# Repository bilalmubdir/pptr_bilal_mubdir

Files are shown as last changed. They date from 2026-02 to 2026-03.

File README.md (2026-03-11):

<table align="center">
  <tr>
    <!-- Left: PNG image (30%) -->
    <td width="30%" align="center" valign="middle">
      
    </td>
    <!-- Right: SVG banner (70%) -->
    <td width="70%" align="center" valign="middle">
      
    </td>
  </tr>
</table>

# Propeller Performance Test Rig Documentation




<div> <a href="https://certification.oshwa.org/uk000089.html"></div>

## 📚 Citation
If you use this repository in academic work:

```bibtex
@misc{pptrBilal2026,
  author       = {Mubdir, Bilal and Prempain, Emmanuel},
  title        = {Propeller Performance Test Rig Documentation},
  month        = mar,
  year         = 2026,
  publisher    = {Zenodo},
  version      = {v1.0.3},
  doi          = {10.5281/zenodo.18955065},
  url          = {https://doi.org/10.5281/zenodo.18955065},
}
```

## 📘 Overview
This repository contains open‑source engineering documentation for the Propeller Performance Test Rig, including mechanical drawings, circuit schematics, block diagrams, and specification tables.

<p align="center">
  
</p>
<!-- The materials accompany the research paper: -->
<!-- 
> **"Propeller Performance Test Rig"**  
> *Author: Bilal Mubdir, Research Postgraduate*  
> *Affiliation: University of Leicester*  
-->

All diagrams and documents are provided under the **CERN Open Hardware License – Strongly Reciprocal (CERN‑OHL‑S)**, enabling transparent reuse and modification for academic and engineering purposes. 

## 📁 Repository Structure
```
docs/
├── figures/
│   ├── mechanical/     # PDFs of CAD, enclosure, and mechanical drawings
│   ├── electrical/     # Circuit schematics, PCB module diagrams
│   └── misc/           # other figures and diagrams
├── CAD/                # The SolidWorks CAD files of the PPTR mechanical design
├── scripts/            # Python Remote Client Application and ESP12F/NodeMCU Firmware
├── lib/                # C++ libraries for the ESP12F/NodeMCU Firmware
└── tables/             # LaTeX tables (specifications, BOM, etc.)
```

## 📄 Contents
#### **Figures**
- Mechanical drawings (exploded views, dimensions)
- Electrical schematics (DAQ, sensors, control modules)
#### **CAD**
- Mechanical design raw CAD files (SolidWorks 2025)
#### **Tables**
- Technical specifications
#### **Scripts**
- Codes and scripts used for the PPTR system 
#### **Libraries**
- C++ libraries for ESP12F/NodeMCU Firmware

## 🛠 Usage
- Access diagrams under `docs/figures/`
- Import tables into your paper from `docs/tables/`

## 📐 Sensor Calibration Instructions (Thrust & Torque Load Cells)
This section provides practical, step‑by‑step instructions for calibrating the thrust load cell and the left/right torque load cells used in the PPTR measurement system.

### 🚀 1. Thrust Load Cell Calibration
The thrust load cell measures vertical thrust generated by the rotor. To calibrate it:

#### 1.1. Setup
* Mount the PPTR vertically (rotor pointing downward).
* Fix the structure onto a rigid support so it cannot move.
* Attach the calibration weight (standard dead load) to the rotor as shown:
<p align="center" >
  
</p>

#### 1.2. Procedure
1) Connect the thrust load cell to its HX711 module.
2) Hang a series of known calibration weights (Loadₛₜd) to generate reference thrust forces.
3) For each weight:
    - Record the raw HX711 output.
    - Remove the weight before applying the next one.

#### 1.3. Result
A linear mapping between Raw load cell voltage, and True thrust force (g)should be computed. The **thrust calibration scale factor** then determined from this mapping.

### 🌀 2. Torque Load Cell Calibration (Left & Right)
The PPTR includes **two torque load cells**, one on each side of the rotor axis. Calibration is performed with the device in its **normal horizontal operating orientation**.

#### 2.1. Setup
* Install the PPTR horizontally on its base.
* Attach the aluminum torque calibration stripe to the calibration lever.
* This stripe has two symmetric holes on each side of the rotor center, at 50 mm and 100 mm. These holes serve as Calibration Reference Points (CRP).
* The calibration process consists of two steps: tare and measure.
<p align="center" >
  
</p>

#### 2.2. Tare Both Torque Load Cells - Step (1)
Before taking any calibration measurements:
1) Place the calibration weight (standard dead load) at CRP‑0 (center of the rotor).
2) Perform a tare (zero) on both channels to nullify rotor, brackets, and any sensor bias.

#### 2.3. Take Calibration Measurements - Step (2)
1) Move the calibration weight to one of the CRPs (50 mm or 100 mm).
2) Record raw left and right torque sensor readings.
3) Move the weight to the symmetric CRP on the opposite side.
4) Repeat measurements using multiple Loadₛₜd values.

This creates symmetric torque reference conditions on both sides

#### 2.4. Result
A linear mapping between Raw load cell voltage and True torque force (N·m) should be computed. The **Torque calibration scale factor** for each sensor is then determined from its corresponding mapping.

<!---->
## 📡 Remote Client Command List
The following commands are used to control the PPTR, operate the motor, read sensors, and perform calibration routines from the Remote Client Application.

| Command |  Syntax  | Description | Input Range / Notes |
|---|---|---|---|
| **Send ESC signal + read sensors** | `CM1,<X>` | Sends ESC control signal *and* reads thrust/torque sensors. | `X = 0–180` (Speed → 0–Max) |
| **Send ESC signal only** | `CM2,<X>` | Drives the ESC without reading sensors. | `X = 0–180` (Speed → 0–Max) |
| **Read sensors only** | `CM3` | Reads thrust and torque sensor values. | No input |
| **ESC calibration routine** | `CM4,<X>` | Used to set ESC calibration points. | `X = 0` → min pulse<br>`X = 1` → max pulse |
| **Tare thrust & torque sensors** | `CM5` | Zeros all load cell readings before measurement. | No input |
| **Safe motor shutdown** | `CM6` | Gradually reduces ESC signal to zero. | No input |
| **Safe motor startup** | `CM7,<X>` | Starts motor safely and ramps signal to target value. | `X = 0–180` (Speed → 0–Max) |
| **System status check** | `CM8` | Reports system status, and safety flags. | No input |

### Notes
- Commands are case-insensitive unless otherwise specified.
- Always run `CM5` (tare) after powering the device or repositioning sensors.
- Calibration (`CM4`) is needed only after replacing ESC or motor hardware.
- Safe start/stop commands (`CM7`, `CM6`) are recommended over issuing raw ESC commands.

## 🧩 Using the Code in This Repository

The PPTR software consists of **two components**:

1) **Python Remote Client Application** (runs on your PC/laptop)  
2) **ESP12F / NodeMCU firmware** (C++ for Arduino IDE)

Both code files are located in:

    docs/scripts/

Required libraries for the firmware are provided in:

    docs/lib/

### 1) Remote Client Application (Python)

**File location**

    docs/scripts/remote_client.py

**What it does**
- Connects to the PPTR’s Wi‑Fi hotspot  
- Sends user commands (CM1–CM8) to the NodeMCU over UDP  
- Streams and plots real‑time sensor data  
- Logs measurements to a CSV file

**Dependencies**

Install the required Python package:

    pip install matplotlib

(Modules `socket`, `time`, `threading`, `queue`, `sys`, and `select` are part of the standard library.)

**Choose the CSV output filename**

Inside the script, edit the line:

    csv_filename = "sensor_data.csv"

Change the value to set the name of your collected data file.

**How to run**

1. Power the PPTR and wait for its Wi‑Fi hotspot.  
2. Connect your computer to:
   
       SSID: ESP-12F/NodeMCU Access Point name
       PASS: chosen password in ESP-12F/NodeMCU Access Point settings

3. Start the client:

       python remote_client.py

4. The script will start plotting live data and append rows to the CSV file.
5. You can send any command from the [command list](#commandsList), except CM3, as this is used continuously to collect data.
6. To stop, type:

       exit

A final static plot will be shown before the program exits.

### 2) ESP12F / NodeMCU Firmware (C++ for Arduino IDE)

**File location**

    docs/scripts/pptr_firmware.cpp

**What it does**

- Creates a Wi‑Fi Access Point and listens for UDP commands  
- Controls the ESC (safe start/stop + direct control)  
- Reads load cells (HX711), tachometer pulses, and INA226 power sensor  
- Streams sensor data back to the Python client

**Arduino libraries (provided)**

All required libraries are included here:

    docs/lib/

Copy everything inside `docs/lib/` to your Arduino libraries folder, restart the Arduino IDE so it detects the libraries.

**Board support and upload (Arduino IDE)**

1. Install the ESP8266 board support:
   
       Arduino IDE → File → Preferences
       Additional Boards Manager URLs:
       http://arduino.esp8266.com/stable/package_esp8266com_index.json

   Then go to:
   
       Tools → Board → Boards Manager → search “ESP8266” → Install

2. Select the board:

       Tools → Board → NodeMCU 0.9 (ESP-12E Module)

3. Open the firmware file and upload:

       File → Open → docs/scripts/pptr_firmware.cpp
       Upload

After upload, the controller will broadcast its hotspot and accept UDP commands.

## 📚 Citation
If you use this repository in academic work:

```bibtex
@misc{pptrBilal2026,
  author       = {Mubdir, Bilal and Prempain, Emmanuel},
  title        = {Propeller Performance Test Rig Documentation},
  month        = mar,
  year         = 2026,
  publisher    = {Zenodo},
  version      = {v1.0.3},
  doi          = {10.5281/zenodo.18955065},
  url          = {https://doi.org/10.5281/zenodo.18955065},
}
```

## 🤝 Contributing
Contributions are welcome!
Please:

- Follow the folder structure
- Include clear commit messages
- Provide PDFs for all figures
<!-- ## 🧩 Maintainers
- Bilal Mubdir
- Research
- Email: bama4@le.ac.uk / bilal.mubdir -->

## License
This project is licensed under the CERN Open Hardware License Version 2 – Strongly Reciprocal (CERN‑OHL‑S).

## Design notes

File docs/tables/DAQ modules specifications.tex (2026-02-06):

\begin{table*}[t]
    \centering
    \footnotesize
    \caption{Summary of modules used in the DAQ system.}
    \begin{tabular}{>{\raggedright}p{3.5cm} >{\centering}p{1.8cm} >{\centering}p{3cm} >{\raggedright\arraybackslash}p{7cm}}
        \toprule
        \bf{Module}  & \bf{Quantity} & \bf{Function} & \bf{Specifications}\\
        \midrule
        NodeMCU & 1 & \thead[c]{Micrcontroller\\and Wi-Fi\\proxy} & \thead[l]{CPU Speed: \SI{160}{\mega\hertz}, Wi-Fi: 802.11 b/g/n, \SI{2.4}{\giga\hertz},\\
                                                                                Memory: 32 Mbit, Voltage: 3-\SI{3.6}{\volt}}\\
                                                                                Interfaces: UART, GPIO, PWM, I$^2$C\\                                      
        CJMCU-266 & 3 & \thead[c]{Measuring\\electrical\\parameters} & \thead[l]{Interface: I$^2$C or SMBus compatible,\\	
                                                                                Measured Voltage: 0-\SI{36}{\volt}, Current Range: \SI{-20}{\milli\ampere} to \SI{20}{\milli\ampere},\\
                                                                                Supply Voltage:	2.7-\SI{5.5}{\volt}, Accuracy: 0.1\% max gain error,\\
                                                                                Max offset:  \SI{10}{\micro\volt}, Resolution:	16-bit for}\\ 
         
        HX711 & 1 & \thead[c]{ADC\\for load cells\\signals} & \thead[l]{ADC Resolution: 24-bit, Input Channels: 2 differential,\\
                                                                                Voltage: 2.6-\SI{5.5}{\volt}, Current: $<$\SI{1.5}{\milli\ampere},\\       
                                                                                Data Rate: up to 80 sample/s,  Interface: Simple 2-wire serial}\\                                                                                               
        \bottomrule
    \end{tabular}
    \label{tab: ch3 DAQ componenets}
\end{table*}

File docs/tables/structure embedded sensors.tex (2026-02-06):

\begin{table}[H]
    \centering
    \footnotesize
    \caption{Summary of the sensors embedded in the PPTR Structure.}
    \begin{tabular}{>{\raggedright}p{1.2cm} >{\centering}p{0.8cm} >{\centering}p{1.7cm} >{\raggedright\arraybackslash}p{2.1cm}}
        \toprule
        \bf{Component}  & \bf{Quantity} & \bf{Function} & \bf{Specifications}\\
        \midrule
        Load cell & 1 & Thurst measurement & \thead[l]{Range: 0-\SI{1}{\kilogram},\\
                                               Voltage: 5-\SI{12}{\volt},\\
                                               Precision: $\mp$\SI{1}{\gram}}\\
        Load cell & 2 & Torque measurement & \thead[l]{Range: 0-\SI{1}{\kilogram},\\
                                               Voltage: 5-\SI{12}{\volt},\\
                                               Precision: $\mp$\SI{1}{\gram}}\\ 
        Infrared sensor & 1 & Rotational speed sensor & \thead[l]{Range: 1-\SI{38}{\kilo\hertz},\\
                                                               Voltage: 3-\SI{5}{\volt},\\
                                                               Detection angle: $35^{\circ}$}\\                             
        \bottomrule
    \end{tabular}
    \label{tab: ch3 PPTR sensors}
\end{table}

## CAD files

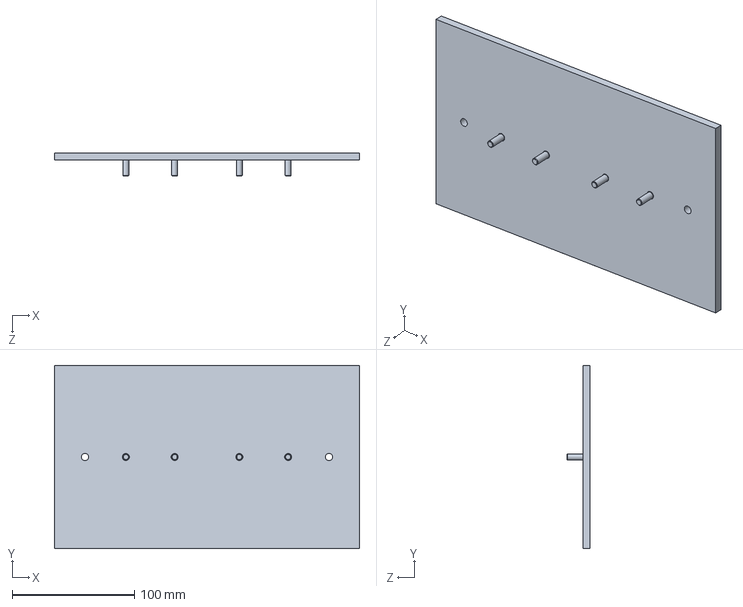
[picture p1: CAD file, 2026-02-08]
docs/CAD/main_base.SLDPRT
250.0 x 150.0 x 19.0 mm

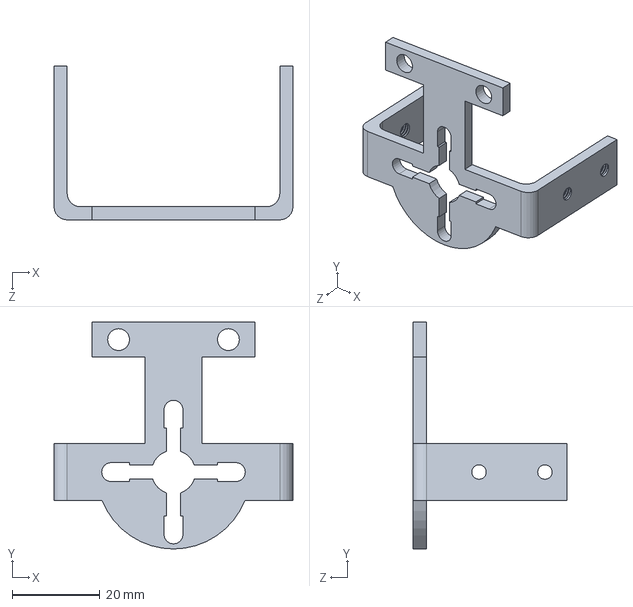
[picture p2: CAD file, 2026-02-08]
docs/CAD/rotor_mounting_bracket.SLDPRT
54.4 x 51.7 x 35.0 mm

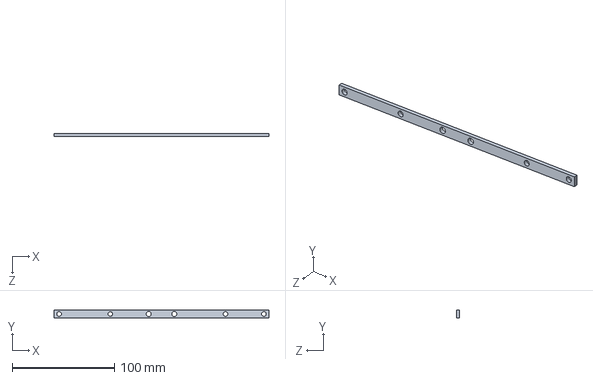
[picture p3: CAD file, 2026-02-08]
docs/CAD/calibration_strip.SLDPRT
210.0 x 8.00 x 3.00 mm

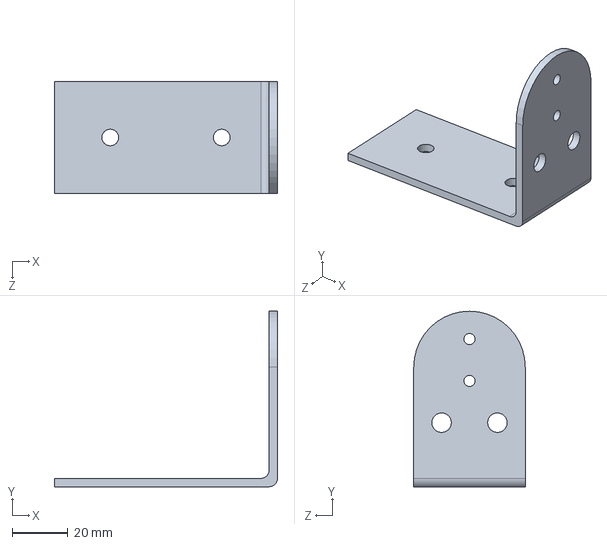
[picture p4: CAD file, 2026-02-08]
docs/CAD/lower_support_brackets.SLDPRT
80.0 x 63.0 x 40.0 mm

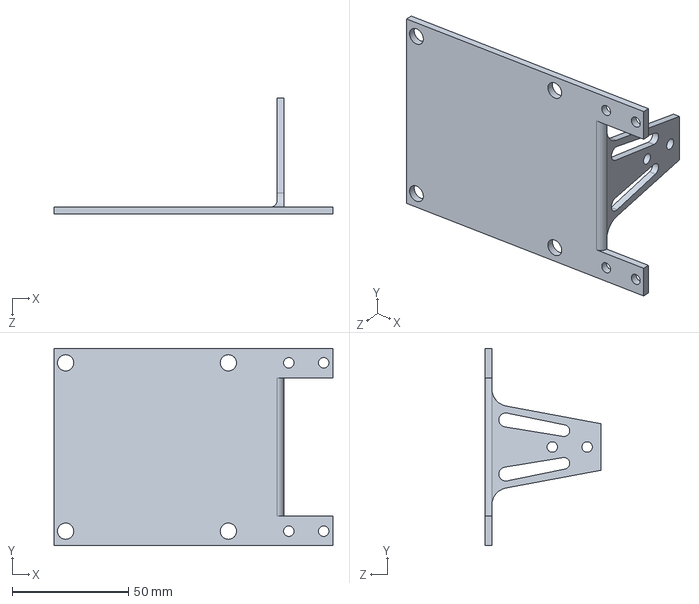
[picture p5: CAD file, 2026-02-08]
docs/CAD/secondary_base.SLDPRT
120.0 x 84.9 x 50.0 mm

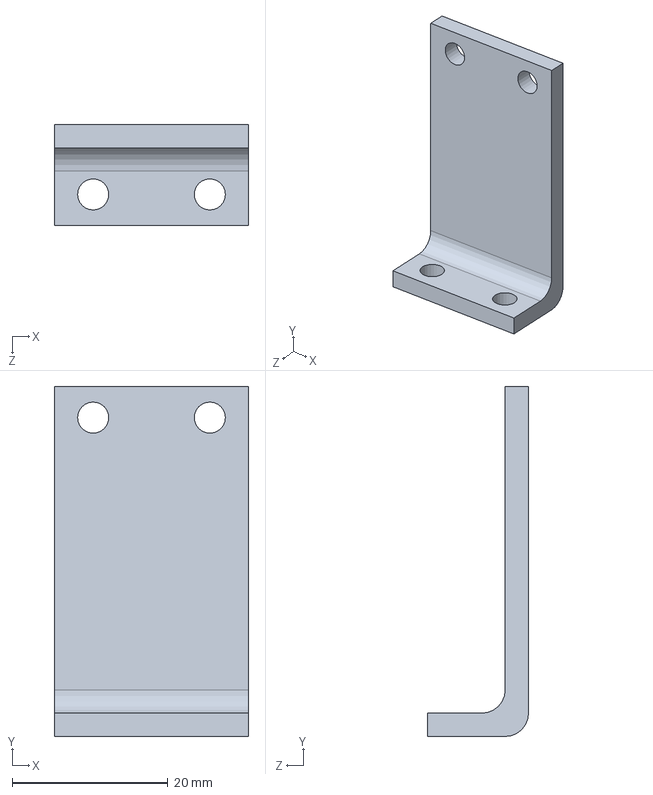
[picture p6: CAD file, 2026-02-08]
docs/CAD/front_support_brackets.SLDPRT
25.0 x 45.0 x 13.0 mm

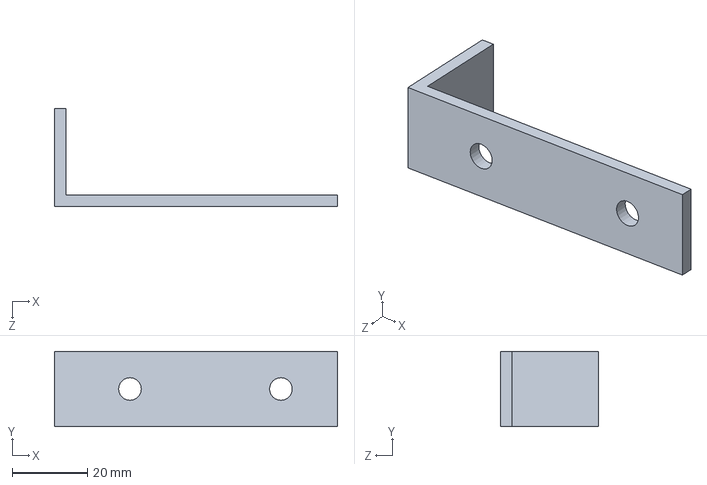
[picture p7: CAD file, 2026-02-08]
docs/CAD/tachometer_bracker.SLDPRT
75.0 x 20.0 x 26.0 mm

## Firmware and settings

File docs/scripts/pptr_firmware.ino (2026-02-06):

#include <ESP8266WiFi.h>
#include <WiFiUdp.h>
#include <Servo.h>
#include <Wire.h>
#include <INA226_WE.h>
#include <HX711_ADC.h>

//////// Network Hotspot Settings ////////////////////////////////
const char* ssid = "Access Point name"; // WiFi SSID
const char* password = "password";        // WiFi password
// UDP Configuration
WiFiUDP udp;   // UDP Server
const unsigned int udpPort = 4210;  // UDP port
char packetBuffer[255]; // Buffer for received packets
IPAddress remoteIP;    // variable for ip address
unsigned int remotePort;  // variable for port
/////////////////////////////////////////////////////////////////


//////// Loadcells Sensors ////////////////////////////////
const int HX711_dout_1 = D5; //mcu > HX711 no 1 dout pin
const int HX711_sck_1 = D0; //mcu > HX711 no 1 sck pin
const int HX711_dout_2 = D6; //mcu > HX711 no 2 dout pin
const int HX711_sck_2 = D0; //mcu > HX711 no 2 sck pin
const int HX711_dout_3 = D7; //mcu > HX711 no 2 dout pin
const int HX711_sck_3 = D0; //mcu > HX711 no 2 sck pin

HX711_ADC LoadCell_1(HX711_dout_1, HX711_sck_1); //HX711 1
HX711_ADC LoadCell_2(HX711_dout_2, HX711_sck_2); //HX711 2
HX711_ADC LoadCell_3(HX711_dout_3, HX711_sck_3); //HX711 3

const int calVal_eepromAdress_1 = 0; // eeprom adress for calibration value load cell 1 (4 bytes)
const int calVal_eepromAdress_2 = 4; // eeprom adress for calibration value load cell 2 (4 bytes)
const int calVal_eepromAdress_3 = 8; // eeprom adress for calibration value load cell 2 (4 bytes)

unsigned long t = 0;
////////////////////////////////////////////////////////////////

////// Pulse Measurement //////////////////////////////////////
volatile unsigned long lastPulseTime = 0; 
volatile unsigned long pulseInterval = 0;
volatile float frequency = 0.0;
volatile float lastFrequency = 0.0;
volatile float RPM = 0.0;
const int PulsesSensPin = D4; 
////////////////////////////////////////////////////////////////


///// Power Measurement ///////////////////////////////////////
#define I2C_ADDRESS 0x40
INA226_WE ina226 = INA226_WE(I2C_ADDRESS);
/////////////////////////////////////////////////////////////

///// ESC Settings //////////////////////////////////////////////////////
Servo ESC;  // create servo object
/////////////////////////////////////////////////////////////////////////

/// Variables /////////////////////////
float shuntVoltage_mV = 0.0;
float loadVoltage_V = 0.0;
float busVoltage_V = 0.0;
float current_mA = 0.0;
float power_mW = 0.0; 
unsigned long stabilizingtime = 5000; // tare preciscion can be improved by adding a few seconds of stabilizing time
boolean _tare = true; //set this to false if you don't want tare to be performed in the next step
byte loadcell_1_rdy = 0;
byte loadcell_2_rdy = 0;
byte loadcell_3_rdy = 0;
String process = "";
String option = "";
//float torque1,torque2,thrust;
String forces = "0.0,0.0,0.0";

///// Display Settings ///////////////////////////////////////
int tm, displayTime = 200;
/////////////////////////////////////////////////////////////

///// Loadcells Sensors //////////////////////////
float calibrationValue_1 = 1500.0; // Right torque sensor calibration scale factor
float calibrationValue_2 = 1500.0; // Left torque sensor calibration scale factor
float calibrationValue_3 = 2159.35; //  Thrust sensor calibration scale factor
/////////////////////////////////////////////////////////////


/////// Pulse Measuring Function /////////////////////////////////////////////////
void IRAM_ATTR countPulse() {
    unsigned long currentTime = micros();
    
    if (lastPulseTime > 0) {  // Ignore first pulse
        unsigned long newInterval = currentTime - lastPulseTime;
        // Ignore spurious pulses with extremely short intervals (e.g., noise)
        float tmp = 1.0 / (newInterval / 1e6);  // Convert µs to seconds
        float diff = abs(tmp - lastFrequency);
        if (newInterval > 500 && diff<=10.0) {  // Minimum interval = 500 µs (Max ~2000 Hz)
            pulseInterval = newInterval;
            frequency = tmp; //1.0 / (pulseInterval / 1e6);  // Convert µs to seconds
            lastFrequency =  frequency;    
        }
    }

    lastPulseTime = currentTime;
}
/////////////////////////////////////////////////////////////////////////////////////




void setup() {
  Serial.begin(115200);
  ESC.attach(D3, 1000, 2000);   /// set the min/max time for the ESC signal
  ESC.write(0);  // Wait for input
  wifi_setup();    // set up the network and start the server
  pinMode(PulsesSensPin, INPUT_PULLUP);  // pulses port
  Serial.println("Wait until all sensors initialized ....");
  ////// Power Measurement ///////////////////////////////////////
  Wire.begin();
  Wire.setClock(20000L);
  if(!ina226.init()){
    Serial.println("Failed to init INA226. Check your wiring.");
    while(1){}
  }
  ina226.setAverage(AVERAGE_256);  // number of samples to be averaged
  ina226.setConversionTime(CONV_TIME_1100); /// convertion time
  ina226.setResistorRange(0.01,20); // choose resistor 5 mOhm and gain range up to 10 A
  ina226.waitUntilConversionCompleted(); //if you comment this line the first data might be zero
  ina226.setCorrectionFactor(1.03); // correction factor used for calibration
  //////////////////////////////////////////////////////////////////////////////////////////////


  ////// Loadcells Sensors //////////////////////////////////////////////////////////////////
  LoadCell_1.begin();
  LoadCell_2.begin();
  LoadCell_3.begin();
  while ((loadcell_1_rdy + loadcell_2_rdy + loadcell_3_rdy) < 3) { //run startup, stabilization and tare, both modules simultaniously
    if (!loadcell_1_rdy) loadcell_1_rdy = LoadCell_1.startMultiple(stabilizingtime, _tare);
    if (!loadcell_2_rdy) loadcell_2_rdy = LoadCell_2.startMultiple(stabilizingtime, _tare);
    if (!loadcell_3_rdy) loadcell_3_rdy = LoadCell_3.startMultiple(stabilizingtime, _tare);
  }
  if (LoadCell_1.getTareTimeoutFlag()) {
    Serial.println("Timeout, check MCU>HX711 no.1 wiring and pin designations");
  }
  if (LoadCell_2.getTareTimeoutFlag()) {
    Serial.println("Timeout, check MCU>HX711 no.2 wiring and pin designations");
  }
  if (LoadCell_3.getTareTimeoutFlag()) {
    Serial.println("Timeout, check MCU>HX711 no.3 wiring and pin designations");
  }
  LoadCell_1.setCalFactor(calibrationValue_1); // user set calibration value (float)
  LoadCell_2.setCalFactor(calibrationValue_2); // user set calibration value (float)
  LoadCell_3.setCalFactor(calibrationValue_3); // user set calibration value (float)
  ////////////////////////////////////////////////////////////////////////////////////////////////////////
  attachInterrupt(digitalPinToInterrupt(PulsesSensPin), countPulse, FALLING);  // Trigger on rising edge
  Serial.println("Initialization is complete");
}


void loop() {
   ///////////////// Loadcells Sensors ///////////////////
   static boolean newDataReady = 0;
   // check for new data/start next conversion:
    if (LoadCell_1.update()) newDataReady = true;
    LoadCell_2.update();
    LoadCell_3.update();
    if ((newDataReady)) {
      float torque1 = LoadCell_1.getData();
      float torque2 = LoadCell_2.getData();
      float thrust = LoadCell_3.getData();
      newDataReady = 0;
      forces = String(torque1) + "," + String(torque2) + "," + String(thrust) ;
    ////////////////////////////////////////////////////////////
  int packetSize = udp.parsePacket();
  if (packetSize) {
     udp.read(packetBuffer, sizeof(packetBuffer));
     packetBuffer[packetSize] = '\0';   // Null terminate the string
     String payload(packetBuffer);
     process = getValue(payload,',', 0);  
     ///// set the motor only  
     if (process=="CM1"){
        option = getValue(payload,',', 1);
        ESC.write(option.toInt());
     }
      ///// set the motor and read sensors OR reading sensors only
     if (process == "CM2"||process == "CM3") {
        // active only when motor is controlled
        if (process == "CM2"){
          option = getValue(payload,',', 1);
          ESC.write(option.toInt());
        }
        remoteIP = udp.remoteIP();     // get the remote ip address
        remotePort = udp.remotePort(); // get the remote udp port
    
        /// Power Measurement Section //////////////////////////////
        shuntVoltage_mV = ina226.getShuntVoltage_mV()*1000;

          // Convert sensor values to a string
          String response = String(frequency) + "," +
                            String(forces) + "," +
                            String(shuntVoltage_mV)+"," +
                            String(busVoltage_V);
        // Send response
        udp.beginPacket(remoteIP, remotePort);
        udp.print(response);
        udp.endPacket();
      }

      if (process=="CM4"){
        Serial.println("Calibrate ESC");
         option = getValue(payload,',', 1);
         ESC_calibration(option.toInt());
      }
      if (process=="CM5"){
         Serial.println("Tare Thrust and Torque Sensors");
         loadcells_tare();
         Serial.println("Tare process completed");
      }
      if (process=="CM6"){
         Serial.println("Safely switching off the motor");
         for (int kk=ESC.read()-1;kk>-1;--kk){
          ESC.write(kk);
          delay(100);
          Serial.println(kk);
         }
         Serial.println("motor is OFF now");
      }
      if (process=="CM7"){
         Serial.println("Safely starting up the motor");
         option = getValue(payload,',', 1);
         for (int kk=ESC.read()+1;kk<option.toInt()+1;++kk){
          ESC.write(kk);
          delay(100);
          Serial.println(kk);
         }
         Serial.println("motor is ON now");
      }
      if (process=="CM8"){
          remoteIP = udp.remoteIP();     // get the remote ip address
          remotePort = udp.remotePort(); // get the remote udp port
          udp.beginPacket(remoteIP, remotePort);
          udp.print("Okay");
          udp.endPacket();
          Serial.println("CM8");
      }   
  }

}



/// ESC Calibration Function ///////////////////////////////////////////////////////
void ESC_calibration(byte pulseSize){
  if (pulseSize==1){
     Serial.println("Now writing maximum output.");
     Serial.println("Turn on power source, then wait 2 seconds and press any key.");
     ESC.write(180);  // Wait for input
  }else{
   ESC.write(0);
    Serial.println("motor is ready now");
  }
}
////////////////////////////////////////////////////////////////////////////////////



////// Loadcells Sensors ////////////////////////////////////
// receive command 't' to initiate tare operation:
void loadcells_tare(){
  LoadCell_1.tareNoDelay();
  LoadCell_2.tareNoDelay();
  LoadCell_3.tareNoDelay();
    //check if last tare operation is complete
  if (LoadCell_1.getTareStatus() == true) {
//    Serial.println("Tare load cell 1 complete");
  }
  if (LoadCell_2.getTareStatus() == true) {
//    Serial.println("Tare load cell 2 complete");
  }
  if (LoadCell_3.getTareStatus() == true) {
//    Serial.println("Tare load cell 3 complete");
  }
}
///////////////////////////////////////////////////////////



//// Setting Up the Network function ////////
void wifi_setup(){
  // Connect to WiFi
  WiFi.softAP(ssid, password);
  Serial.println(" ");
  Serial.println("Access Point Started");
  Serial.print("IP Address: ");
  Serial.println(WiFi.softAPIP());

  // Start UDP Server
  udp.begin(udpPort);
  Serial.print("Listening on UDP port ");
  Serial.println(udpPort);
}
/////////////////////////////////////////////


/// Parsing data function //////////////////////////////
String getValue(String data, char separator, int index)
{
  int found = 0;
  int strIndex[] = {0, -1};
  int maxIndex = data.length()-1;

  for(int i=0; i<= maxIndex && found<=index; i++){
    if(data.charAt(i)==separator || i==maxIndex){
        found++;
        strIndex[0] = strIndex[1]+1;
        if (i == maxIndex){
          strIndex[1] = i+1;
        }
        else {strIndex[1] = i;}
    }
  }
  if (found>index){
    return data.substring(strIndex[0], strIndex[1]);
  }
  else { return "";} 
}
////////////////////////////////////////////////////////////

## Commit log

2026-02-06 modified: .github/workflows/latex.yml modified: .gitignore modified: .zenodo.json modified: README.md modified: banner.svg modified: docs/lib/INA226_WE/INA226_WE/examples/Continuous/Continuous.ino mo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
2026-02-08 CAD raw files for the mechanical design included in docs/CAD modified: README.md new file: docs/CAD/calibration_strip.SLDPRT new file: docs/CAD/front_support_brackets.SLDPRT new file: docs/CAD/lower_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
    [calibration_strip.SLDPRT, front_support_brackets.SLDPRT, lower_support_brackets.SLDPRT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]

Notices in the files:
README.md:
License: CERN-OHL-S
